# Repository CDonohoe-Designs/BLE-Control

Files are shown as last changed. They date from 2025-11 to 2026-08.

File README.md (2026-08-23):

# BLE-Control — Wearable BLE Controller

BLE-Control is a compact, low-power wearable controller built around the STM32WB55 (BLE 5 + Cortex-M4/M0+), designed with robust power delivery, RF performance, USB-C protection, and sensor interfacing in mind. The system includes a protected USB-C charging front end (PPTC, TVS, CMC, ESD), a TI BQ21061 charger/power-path, a clean 3.3 V system rail from TPS7A02, and a switchable sensor domain feeding TMP117, BMI270, and SHTC3. 

## PCB Render

<p align="center">
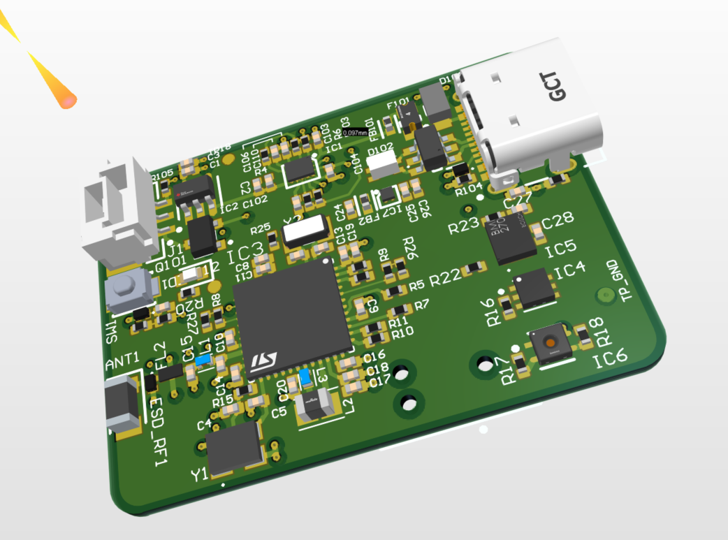
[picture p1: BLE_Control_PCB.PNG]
BLE Control PCB 3D render
  
</p>

## 2-Minute Engineering Review

I designed BLE-Control as a compact **low-power BLE wearable controller** that brings together power-path design, RF integration, USB-C protection, sensors and embedded bring-up considerations on one platform.

### Engineering focus

- **BLE embedded platform** — STM32WB55 dual-core MCU/radio architecture with SWD programming and BLE bring-up path
- **Power architecture** — BQ21061 charger/power path, low-noise 3.3 V regulation and a switchable sensor rail
- **USB-C robustness** — PPTC, TVS, ESD protection, common-mode filtering and controlled shield treatment
- **RF design intent** — STM32WB55 RF output, differential filtering, π-match provision, chip antenna and controlled RF routing strategy
- **Sensor integration** — TMP117, BMI270 and SHTC3 on a gated low-power domain
- **Bring-up planning** — staged verification of power, programming, charger, sensors, SMPS and RF performance
- **Design-for-test / EMC thinking** — test points, interface protection, return paths and pre-compliance checks considered during the hardware design

### Quick review

- **[Hardware / Altium source](Hardware/Altium/)**
- **[Documentation index](Docs/README.md)**
- **[Firmware area](Firmware/)**
- **[PCB render](BLE_Control_PCB.PNG)**

---

## ✔ Work Completed (More to do!)

## Project status

**Last updated:** _Nov 2025_ Summary

- ✅ **Schematic design**: Rev-A hierarchy complete (charger/LDO, MCU & RF, USB/debug, sensors, IO/buttons, testpoints).
- ✅ **First-pass BOM + docs**: Markdown BOM and design notes under `docs/`.
- ✅ **Standards & process docs**: ISO 13485 / ISO 14971 packs started; EMC/IEC alignment notes drafted.
- 🔄 **PCB layout (AD25)**: Stack-up and floorplanning in progress; routing and EMC tuning next.
- 🔄 **Design reviews**: EVT Rev-A sign-off checklists being filled in (schematic + PCB).
- ⏳ **Firmware & bring-up**: Basic STM32WB CubeIDE project to follow once PCB layout stabilises.

### **Hardware Design**
- Complete schematic capture in **Altium Designer 25**
- Power architecture finalised:
  - USB-C entry protection (PPTC, TVS, USBLC6, CMC, shield bleed)
  - BQ21061 charger/power-path wired and validated in schematic
  - TPS7A02-3.3 system rail finalised
  - TPS22910A sensor rail gating implemented
- Full RF chain designed:
  - STM32WB55 RF output → differential filter → π-match (DNP default) → chip antenna
  - CPWG routing strategy + via-fence defined
- Sensors subsystem defined (BMI270, TMP117, SHTC3)
- Tag-Connect TC2030-NL debug interface integrated

### **Documentation**
- `/Docs` folder structured like a mini Design History File

---

## My Roadmap

### **1. PCB Layout in Altium AD25**
- Stack-up definition (1.6 mm, 4-layer)
- Impedance-controlled CPWG for RF output
- SMPS layout (tight loop, ground islanding)
- USB-C differential routing & ESD return paths
- EMC placement discipline (TVS close to entry, CMC orientation, return paths)
- Placement of sensors & service loops for testing
- Test point optimisation

### **2. PCB DRC/EMC Review**
- High-speed/EMC checks (Rick Hartley rules)
- Return path verification
- Split of quiet vs noisy ccts
- Thermal considerations for charger IC

### **3. IEC / ISO Documentation Expansion**
- Full 60601-1 safety narrative 
- 60601-1-2 immunity for each port
- ISO 14971: expand risk register and residual risk justification
- ISO 13485: early DHF structure (revision control, traceability)

### **4. Firmware Bring-Up**
- Standby → Active → Sensor acquisition flow
- BLE service creation (GATT)
- BQ21061 telemetry/status decoding
- IMU & environmental sensing
- RF PER testing via CubeMonitor-RF

### **5. Pre-Compliance Preparation**
- Test plan for ESD/EFT/surge
- RF pre-scan (harmonics, match tuning)
- Power integrity measurements

This roadmap is updated as design work continues.

---

# Quick Navigation

###  Full Documentation 
→ **[`Docs/README.md`](Docs/README.md)**  
Structured like a mini **Design History File (DHF)**:

- Schematic (master PDF + overview)  
- Medical-style BoM + component-criticality  
- Safety boundary & 60601 rationale  
- EMC notes & port classification  
- Risk register (ISO 14971)  
- Battery pack documentation  
- Bring-up + AD25 rules

---

###  Hardware (Altium AD25)
→ **[`Hardware/Altium/`](Hardware/Altium/)**  

Includes:

- Complete AD25 project (`.PrjPcb`, `.SchDoc`, `.PcbDoc`)  
- Outputs, Draftsman drawings, OutJobs  
- Component libraries  
- SmartPDF source

---

###  Firmware (STM32WB55)
→ **[`Firmware/`](Firmware/)**  

- STM32CubeIDE project  
- BLE stack integration (CPU2 Wireless Coprocessor)  
- Startup & bring-up code  
- Board support notes

---

#  System Overview

BLE-Control contains three core domains:

### 1. Power / Charging / USB-C

- **BQ21061** charger/power-path  
- Reverse-battery PMOS  
- **TPS7A02-3.3** → `+3V3_SYS`  
- **TPS22910A** → `3V3_SENS` (gated sensor rail)  
- USB-C hardened with:  
  - PPTC  
  - VBUS TVS  
  - CC ESD  
  - USBLC6  
  - Common-mode choke  
  - Shield bleed `1 MΩ // 1 nF C0G`  

### 2. MCU + RF (STM32WB55)

- Dual-core + BLE 5  
- USB FS with 22 Ω series  
- 32 MHz HSE + 32.768 kHz LSE  
- On-chip SMPS with 10 µH + (optional 10 nH helper)  
- RF feed → π-match (DNP default) → Johanson antenna  
- SWD via **Tag-Connect TC2030-CTX-NL**

### 3. Sensors + I/O

- TMP117 (precision temperature)  
- BMI270 (IMU)  
- SHTC3 (humidity/T)  
- All on **3V3_SENS** gated by MCU  
- Button with ESD + RC + 100 Ω  
- LED indicator (active-low)  

---

#  Design-for-Compliance Highlights

*(Not certified; reflects professional habits and design intent)*

### IEC 60601-1 (Basic safety & essential performance)

- Full SELV design (<5.0 V)  
- Battery safety via BQ21061 + pack NTC  
- Reverse battery protection  
- Defined essential performance: **BLE command/control**

### IEC 60601-1-2 (Ed.4) EMC

- Classified ports (USB, button, sensor rail, RF)  
- Surge/ESD/EFT protection at USB entry  
- Segmented power domains for immunity (`3V3_SYS` vs `3V3_SENS`)  
- RF/SMPS layout discipline based on ST AN5165  

### ISO 14971 (Risk)

- Full risk register included  
- Hazards mapped to hardware controls  
- Residual-risk evaluation  
- Precompliance EMC test strategy  

### ISO 13485 (Documentation style)

Repo mirrors a simplified DHF structure:

```text
Docs/
  Schematic/
  BoM/
  Compliance/
  Risk/
  Battery/
  Reports/
  testing/
```

---
#  BLE-Control — Bring-Up & Testing Summary

This document captures the recommended bring-up flow and key test procedures for the BLE-Control hardware platform.

##  Bring-Up Order

### 1. **Verify Power Path & Rails**
- Power via USB-C or bench supply.
- Confirm:
  - `VBUS`
  - `VBAT_RAW`
  - `VBAT_PROT`
  - `PMID`
  - `+3V3_SYS` (TPS7A02 output)
- Check for ripple, inrush anomalies, or unstable startup.

### 2. **Flash STM32WB55 (SMPS-bypass mode)**
- Leave SMPS inductors populated or install 0 Ω bypass links.
- Program using Tag-Connect TC2030-CTX-NL.
- Load minimal firmware (heartbeat LED + UART/SWV optional).

### 3. **Enable Charger & Monitor `BQ_INT`**
- Validate:
  - USB attachment detection
  - Correct CC pull-down behaviour
  - BQ21061 charge state transitions
  - `BQ_INT` on MCU (falling-edge EXTI)

### 4. **Bring Up Sensors (`SENS_EN` → `3V3_SENS`)**
- Assert `SENS_EN` → TPS22910A enables the sensor rail.
- Confirm correct voltage and soft-start behaviour.
- Check I²C access to:
  - TMP117
  - BMI270
  - SHTC3

### 5. **Enable SMPS & Verify Ripple**
- Populate SMPS inductors (10 µH + optional 10 nH helper).
- Remove any bypass 0 Ω links if used.
- Measure ripple on:
  - `VLXSMPS`
  - `VDD`
  - `+3V3_SYS`

### 6. **RF Bring-Up + π-Match Tuning**
- Conduct preliminary RF tests:
  - Return-loss sweep of antenna
  - Harmonic scan
  - π-match population depending on results

### 7. **Run STM32CubeMonitor-RF PER Tests**
- Validate BLE link margin.
- Test across multiple channels.
- Measure Packet Error Rate (PER) at various distances and orientations.

---

##  EMC Pre-Compliance Checklist

### **IEC 61000-4-2 (ESD)**
- ±8 kV contact  
- ±15 kV air  
- Test:
  - USB shield
  - Button
  - Enclosure reference points

### **IEC 61000-4-4 (Burst/EFT)**
- ±1 kV at VBUS entry (through external PSU)

### **IEC 61000-4-3 (Radiated Immunity)**
- 10 V/m, 80 MHz–2.7 GHz  
- Observe:
  - BLE stability (RSSI)
  - Sensor I²C errors
  - Reset line behaviour
  - Spurious interrupts

### **IEC 61000-4-6 (Conducted RF Immunity)**
- 3 Vrms, 150 kHz–80 MHz  
- Monitor:
  - BLE performance  
  - I²C bus integrity  
  - Power rail droop

---

##  Tools Used

- **Altium Designer 25**  
- **STM32CubeIDE / STM32CubeProgrammer**  
- **LTspice / Python** (signal analysis, power ripple, FFT, etc.)  
- **STM32CubeMonitor-RF** (BLE PER, RSSI, channel sweep)  

---

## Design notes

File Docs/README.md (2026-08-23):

# BLE-Control — Documentation Index (`/Docs`)

This folder contains the supporting engineering documentation for the **BLE-Control low-power BLE sensor platform**.

The repository is organised as a practical portfolio / development record rather than a formal regulated-product technical file.

## Contents

- **Battery/** — battery pack requirements and interface notes
- **BoM/** — bill of materials and component information
- **Datasheets/** — manufacturer references and datasheet links
- **PCB/** — PCB-related notes and images
- **Reviews/** — schematic/design review checklists and follow-up actions
- **Schematic/** — exported schematic PDF

The documentation supports the hardware design, bring-up planning and verification work described in the main repository README.

> **Status:** engineering R&D / portfolio project. Not a certified or qualified medical device.

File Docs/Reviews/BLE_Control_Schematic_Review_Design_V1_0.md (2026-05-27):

# BLE-Control Schematic Design Review — Design Owner Checklist

**Project:** BLE-Control Wearable  
**Review Type:** Schematic Design Review  
**Review Basis:** BLE-Control schematic PDF, Altium schematic files, and PCB design file  
**Reviewer:** Caoilte Donohoe  
**Date:** 2026-05-27  
**Revision:**  A0 (EVT)

**Status:** Design-owner schematic review. Items marked as actions are follow-up checks before final release.

**Review Note:** This checklist records my  schematic review of the BLE-Control design. The ticked items indicate areas I reviewed against the schematic, with follow-up actions captured where further Altium, BOM, footprint, layout, or bring-up checks are required.

---

# 1. Documentation & Architecture

- [x] Reviewed  [ ] N/A — Schematic hierarchy is logical and easy to navigate  
  **My review:** Pass. The design is split into clear functional sheets: power/USB/charger, MCU/RF, and sensors/I/O.

- [x] Reviewed  [ ] N/A — Functional blocks are clearly separated  
  **My review:** Pass. Power, USB, charger, BLE RF, MCU, sensors, button and LED blocks are clearly grouped.

- [x] Reviewed  [ ] N/A — Design intent notes are included where appropriate  
  **My review:** Pass. Useful notes are included for BLE RF, USB protection, charger behaviour, BOOT0, SWD and sensor rail control.

- [x] Reviewed  [ ] N/A — Sheet titles and references are consistent  
  **My review:** Minor issue. Overall title structure is good, but the sensor sheet title/file text appears to contain a typo: `SchDDocrawn By`.  
  **My follow-up:** Clean up title block text before release.

- [x] Reviewed  [ ] N/A — Interfaces between sheets are clearly defined  
  **My review:** Pass. Cross-sheet signal labels are present for USB, I²C, sensor enable, interrupts, button and LED.

- [x] Reviewed  [ ] N/A — External interfaces are documented  
  **My review:** Pass. USB-C, battery connector, SWD and RF antenna sections are identifiable.

---

# 2. Power Architecture

- [x] Reviewed  [ ] N/A — Power architecture is clearly defined  
  **My review:** Pass. Main rails and sensor rail are understandable.

- [x] Reviewed  [ ] N/A — All supply rails have identified sources  
  **My review:** Pass. USB/VIN charging path, battery path, main 3V3 and gated sensor 3V3 are shown.

- [x] Reviewed  [ ] N/A — Voltage levels are appropriate for all devices  
  **My review:** Pass, with follow-up check. 3V3 system rail appears appropriate for MCU and sensors.  
  **My follow-up:** Check low-battery behaviour of the 3V3 LDO, as a single Li-ion cell may fall close to or below regulation headroom.

- [x] Reviewed  [ ] N/A — No missing power connections  
  **My review:** Pass, subject to compile check. Power pins are shown on visible symbols.  
  **My follow-up:** Run Altium compile/ERC and confirm.

- [x] Reviewed  [ ] N/A — Input protection strategy reviewed  
  **My review:** Pass. USB input includes PPTC, TVS/ESD and filtering.

- [x] Reviewed  [ ] N/A — Regulator enable behaviour reviewed  
  **My review:** Pass. LDO enable is tied to input and documented as always-on.

- [x] Reviewed  [ ] N/A — Startup behaviour reviewed  
  **My review:** Pass, with follow-up check. BOOT0, reset and sensor enable defaults are documented.  
  **My follow-up:** Confirm reset timing and firmware default states during bring-up.

---

# 3. Battery & Charging

- [x] Reviewed  [ ] N/A — Battery charging architecture reviewed  
  **My review:** Pass. Stand-alone Li-ion charger architecture is clear.

- [x] Reviewed  [ ] N/A — Charge current is appropriate  
  **My review:** Pass, with follow-up check. Charge current is documented as approximately 100 mA.  
  **My follow-up:** Check this matches intended battery capacity and charge-time expectations.

- [x] Reviewed  [ ] N/A — Battery connector reviewed  
  **My review:** Pass. Battery connector and protected battery node are shown.

- [x] Reviewed  [ ] N/A — NTC / temperature monitoring reviewed  
  **My review:** Pass, with follow-up check. Battery NTC connection is shown.  
  **My follow-up:** Confirm NTC divider/charger thermistor thresholds against battery pack datasheet.

- [x] Reviewed  [ ] N/A — Charger status signals reviewed  
  **My review:** Pass. PG/STAT signals are exposed and pulled up for debug.

- [x] Reviewed  [ ] N/A — Battery and charger test points included  
  **My review:** Pass. Charger status and power path test points are included.

---

# 4. MCU Review

- [x] Reviewed  [ ] N/A — MCU power pins connected correctly  
  **My review:** Pass, subject to compile check. Multiple VDD domains, RF supply and USB supply are shown.  
  **My follow-up:** Check against STM32WB55 reference design and ERC.

- [x] Reviewed  [ ] N/A — Decoupling strategy implemented  
  **My review:** Pass. Local 100 nF and bulk decoupling capacitors are included.

- [x] Reviewed  [ ] N/A — Reset circuit reviewed  
  **My review:** Pass. Pull-up and reset capacitor are shown.

- [x] Reviewed  [ ] N/A — Boot configuration reviewed  
  **My review:** Pass. BOOT0 is pulled down and documented.

- [x] Reviewed  [ ] N/A — Clock circuits reviewed  
  **My review:** Pass, minor issue noted. HSE and LSE circuits are shown.  
  **My follow-up:** Fix apparent capacitor value text typo: `10Fp` should likely be `10pF`. Check all crystal load capacitors against the crystal datasheet and STM32WB reference design.

- [x] Reviewed  [ ] N/A — Debug/programming interface included  
  **My review:** Pass. SWD/Tag-Connect service port is included.

- [x] Reviewed  [ ] N/A — Unused pins strategy considered  
  **My review:** Pass. Note states unused GPIO configured as analog/no-pull in firmware.

---

# 5. USB Interface

- [x] Reviewed  [ ] N/A — USB-C configuration reviewed  
  **My review:** Pass for USB 2.0 device/sink style implementation.

- [x] Reviewed  [ ] N/A — CC pin configuration reviewed  
  **My review:** Pass. CC pull-down resistors are included.

- [x] Reviewed  [ ] N/A — USB ESD protection included  
  **My review:** Pass. USB data and CC ESD protection are included.

- [x] Reviewed  [ ] N/A — USB filtering reviewed  
  **My review:** Pass, with follow-up check. Common-mode choke is included.  
  **My follow-up:** Check selected CMC is suitable for USB full-speed signalling and does not degrade eye margin.

- [x] Reviewed  [ ] N/A — VBUS protection reviewed  
  **My review:** Pass. VBUS includes fuse and TVS protection.

- [x] Reviewed  [ ] N/A — USB data path reviewed  
  **My review:** Pass, with follow-up check. Series resistors are included at MCU side.  
  **My follow-up:** Check USB-C D+/D− A/B side connection symmetry and differential routing in PCB.

---

# 6. RF / BLE Review

- [x] Reviewed  [ ] N/A — RF signal path clearly defined  
  **My review:** Pass. STM32WB RF pin routes through matching/filtering to chip antenna.

- [x] Reviewed  [ ] N/A — Antenna selection reviewed  
  **My review:** Pass, with follow-up check. Chip antenna is included.  
  **My follow-up:** Check board thickness, ground clearance and antenna keepout match antenna datasheet.

- [x] Reviewed  [ ] N/A — RF matching network included  
  **My review:** Pass. Matching/filter components are included.

- [x] Reviewed  [ ] N/A — RF ESD protection included  
  **My review:** Pass, with follow-up check. RF ESD footprint is included.  
  **My follow-up:** Check RF ESD capacitance is low enough for 2.4 GHz operation and locate close to antenna/RF entry as intended.

- [x] Reviewed  [ ] N/A — Controlled impedance requirement documented  
  **My review:** Pass. RF path is labelled as 50 ohm / CPWG intent.

- [x] Reviewed  [ ] N/A — Antenna keepout requirement documented  
  **My review:** Pass, with follow-up check. RF notes exist.  
  **My follow-up:** Check keepout in the PCB file against antenna datasheet.

- [x] Reviewed  [ ] N/A — RF grounding strategy considered  
  **My review:** Pass. Via fence / CPWG strategy is documented.

- [x] Reviewed  [ ] N/A — EMC / radiated emissions strategy considered  
  **My review:** Pass. RF and IEC 60601-1-2 intent notes are included.

---

# 7. Sensors & Interfaces

- [x] Reviewed  [ ] N/A — I²C bus architecture reviewed  
  **My review:** Pass. I²C bus connects MCU, temperature sensor and IMU.

- [x] Reviewed  [ ] N/A — Pull-up strategy reviewed  
  **My review:** Pass. Pull-ups are connected to gated sensor rail.

- [x] Reviewed  [ ] N/A — Address conflicts checked  
  **My review:** Reviewed, follow-up required. Address pins are visible, but full address review requires datasheets.  
  **My follow-up:** Confirm TMP117 and BMI270 I²C addresses do not conflict.

- [x] Reviewed  [ ] N/A — Sensor power requirements reviewed  
  **My review:** Pass. Sensors are powered from gated 3V3 sensor rail.

- [x] Reviewed  [ ] N/A — Sensor enable strategy reviewed  
  **My review:** Pass. Sensor rail is controlled through load switch.

- [x] Reviewed  [ ] N/A — Interrupt handling reviewed  
  **My review:** Pass, with follow-up check. Interrupt lines are shown.  
  **My follow-up:** Check required pull-ups/pull-downs and firmware configuration.

---

# 8. User Interface

- [x] Reviewed  [ ] N/A — Button default states defined  
  **My review:** Pass. Pull network and default state are documented.

- [x] Reviewed  [ ] N/A — Button debounce strategy reviewed  
  **My review:** Pass. RC filtering is included.

- [x] Reviewed  [ ] N/A — Button ESD protection included  
  **My review:** Pass. TVS/ESD diode is included.

- [x] Reviewed  [ ] N/A — LED current limiting reviewed  
  **My review:** Pass. LED resistor is included.

- [x] Reviewed  [ ] N/A — LED drive method reviewed  
  **My review:** Pass. LED is MCU-controlled.

- [x] Reviewed  [ ] N/A — LED default state reviewed  
  **My review:** Pass, with follow-up check.  
  **My follow-up:** Check firmware default GPIO state prevents unwanted LED current during reset.

---

# 9. EMC / ESD Review

- [x] Reviewed  [ ] N/A — External interfaces protected  
  **My review:** Pass. USB, button and RF interfaces include protection.

- [x] Reviewed  [ ] N/A — Human-accessible interfaces protected  
  **My review:** Pass. USB and button include ESD protection.

- [x] Reviewed  [ ] N/A — RF interface protected  
  **My review:** Pass, with follow-up check. RF ESD is included.

- [x] Reviewed  [ ] N/A — USB interface protected  
  **My review:** Pass. USB ESD/TVS/fuse/CMC are present.

- [x] Reviewed  [ ] N/A — Filtering strategy reviewed  
  **My review:** Pass. USB filtering, ferrite beads and RF filtering are included.

- [x] Reviewed  [ ] N/A — Noise-sensitive circuits identified  
  **My review:** Pass. RF, crystal and sensor sections are identifiable.  
  **My follow-up:** Check layout keeps RF/crystal loops short and away from noisy USB/power paths.

---

# 10. Grounding Strategy

- [x] Reviewed  [ ] N/A — Grounding philosophy documented  
  **My review:** Pass. Notes refer to RF grounding, CPWG and via fence.

- [x] Reviewed  [ ] N/A — Digital return paths considered  
  **My review:** Reviewed, to confirm during PCB review.  
  **My follow-up:** Confirm solid L2 ground plane and no routing across return path gaps.

- [x] Reviewed  [ ] N/A — RF grounding considered  
  **My review:** Pass with PCB verification required.  
  **My follow-up:** Check RF via fence, antenna keepout and matching network grounding in layout.

- [x] Reviewed  [ ] N/A — Shielding requirements identified  
  **My review:** Not currently required for this BLE-Control prototype unless enclosure or system shielding is added later.

- [x] Reviewed  [ ] N/A — No obvious unintended ground issues identified  
  **My review:** Pass, subject to compile check.  
  **My follow-up:** Check with compiled project/net connectivity.

---

# 11. Testability

- [x] Reviewed  [ ] N/A — Power rail test points available  
  **My review:** Pass. Main rails and charger nodes have test points.

- [x] Reviewed  [ ] N/A — Ground test points available  
  **My review:** Pass. Ground test point is included.

- [x] Reviewed  [ ] N/A — Debug access available  
  **My review:** Pass. SWD connector is included.

- [x] Reviewed  [ ] N/A — Key signals accessible  
  **My review:** Pass. Charger status, boot, sensor enable and rails are accessible.

- [x] Reviewed  [ ] N/A — Programming method defined  
  **My review:** Pass. SWD/Tag-Connect is documented as service port.

- [x] Reviewed  [ ] N/A — Manufacturing test access considered  
  **My review:** Pass for prototype.  
  **My follow-up:** For production, define fixture access, programming flow and minimum functional test.

---

# 12. Reliability & Robustness

- [x] Reviewed  [ ] N/A — Safe startup behaviour reviewed  
  **My review:** Pass. BOOT0, reset and sensor enable behaviour are documented.

- [x] Reviewed  [ ] N/A — Safe shutdown behaviour reviewed  
  **My review:** Reviewed, follow-up required.  
  **My follow-up:** Check firmware handles low battery and charger connection behaviour.

- [x] Reviewed  [ ] N/A — Brownout conditions considered  
  **My review:** Reviewed, follow-up required.  
  **My follow-up:** Check STM32 brownout/reset configuration and low-battery behaviour.

- [x] Reviewed  [ ] N/A — Fault behaviour reviewed  
  **My review:** Pass at schematic level. Sensor rail can be disabled.

- [x] Reviewed  [ ] N/A — Recovery behaviour reviewed  
  **My review:** Pass, with follow-up check. SWD and BOOT0 recovery path are available.

---

# 13. Manufacturing Readiness

- [x] Reviewed  [ ] N/A — Components available from suitable suppliers  
  **My review:** Reviewed, BOM follow-up required.  
  **My follow-up:** Review lifecycle, lead time and alternates.

- [x] Reviewed  [ ] N/A — Lifecycle risk reviewed  
  **My review:** Reviewed, BOM follow-up required.  
  **My follow-up:** Add lifecycle and AVL review before release.

- [x] Reviewed  [ ] N/A — Footprints verified  
  **My review:** Reviewed, footprint/library follow-up required.  
  **My follow-up:** Verify all footprints against datasheets, especially USB-C, antenna, STM32 package, charger, load switch and connectors.

- [x] Reviewed  [ ] N/A — Assembly risks identified  
  **My review:** Reviewed, PCB/DFM follow-up required.  
  **My follow-up:** Check small passives, USB-C solderability, antenna clearance and connector accessibility.

- [x] Reviewed  [ ] N/A — Special manufacturing requirements identified  
  **My review:** Partially reviewed. RF antenna/matching and USB-C assembly need specific DFM attention.

---

# 14. Key Review Findings

## Major Issues

- [x] No major schematic issues identified in my review.
- [ ] Issue: _______________________________________

## Minor Issues / Fix Before Release

- [x] Fix apparent title block typo on sensor sheet.
- [x] Check apparent capacitor value text typo: `10Fp` should likely be `10pF`.
- [x] Check USB-C D+/D− A/B side connectivity and routing symmetry.
- [x] Check RF antenna keepout, ground clearance and antenna reference layout.
- [x] Confirm crystal load capacitors against crystal and STM32WB55 requirements.
- [x] Confirm LDO dropout/headroom at low battery voltage.
- [x] Run Altium compile/ERC and resolve all relevant warnings/errors.
- [x] Verify all footprints against component datasheets.
- [x] Generate BOM/lifecycle/AVL review.

## Recommendations

- [x] Add a short `Review Notes` section to the repository explaining that this is an EVT non-medical wearable prototype.
- [x] Export ERC report from Altium and store it with this checklist.
- [x] Export schematic PDF and PCB screenshots after each release tag.
- [x] Add a small production/bring-up checklist covering first power-up, SWD programming, BLE test, USB test, charger test and sensor I²C scan.

---

# Final Sign-Off

| Reviewer | Role | Status | Date |
|---|---|---|---|
| Caoilte Donohoe | Design Owner | [ ] Approved [x] Conditional [ ] Reject | 2026-05-27 |
| Reviewer 2 | Peer Reviewer | [ ] Approved [ ] Conditional [ ] Reject | __________ |

**Conditional Approval Note:**  
I consider the schematic suitable for prototype/EVT progression, subject to Altium compile/ERC, footprint verification, RF antenna layout check, USB-C connectivity check, and BOM/lifecycle review.

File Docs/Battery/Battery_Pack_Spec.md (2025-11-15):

# BLE-Control Battery Pack Specification

**Type:** Single-cell Li-ion polymer (3.7 V nom, 4.2 V max)  
**Capacity:** 300–500 mAh (target ~400 mAh)  
**Wires:** 3-wire (VBAT+, GND, 10 k NTC @25 °C, B≈3435)  
**Protection:** Integrated PCM (OVP/UVP/OCP/short)  
**Connector:** JST-GH, 3-pin (Board: BM03B-GHS-TBT; Cable: GHR-03V-S + SSHL-003GA-P0.2)

## Compliance & Documentation (Required)
- IEC 62133-2 certificate/report (cell or pack)
- UN 38.3 transport test report
- UL 2054 (or equivalent safety report) – preferred for pack
- MSDS, RoHS/REACH, CoC, traceability labels

## Electrical
- Max charge voltage: 4.2 V
- Recommended charge current: 0.2–0.5 C
- Discharge current: ≥0.2 A continuous, ≥0.5 A peak
- Operating temp (charge): 0…45 °C (JEITA via BQ21061 TS)
- Storage temp: –20…45 °C

## Pinout (J102 / JST-GH-3)
1: VBAT+ (red)  
2: GND (black)  
3: NTC 10 k (white)

## Notes
- Pack NTC is mandatory for medical-minded design; the charger TS pin reads pack temperature for JEITA-safe charging.
- Harness length: 50–150 mm, strain-relieved.

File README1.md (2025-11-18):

# BLE-Control — Wearable BLE Controller

BLE-Control is a compact, low-power wearable controller built around the STM32WB55 (BLE 5 + Cortex-M4/M0+), designed with robust power delivery, RF performance, USB-C protection, and sensor interfacing in mind. The system includes a protected USB-C charging front end (PPTC, TVS, CMC, ESD), a TI BQ21061 charger/power-path, a clean 3.3 V system rail from TPS7A02, and a switchable sensor domain feeding TMP117, BMI270, and SHTC3. It acts as an external BLE-enabled controller/companion board suitable for wearable, low-profile and medically-aligned designs.

This is a portfolio/showcase project with **design-for-compliance** habits intentionally aligned to **IEC 60601-1** (basic safety & essential performance), **IEC 60601-1-2 Ed.4** (EMC, Class A), and documentation practices informed by **ISO 13485** (QMS) and **ISO 14971** (risk).  
The repository mirrors a lightweight **Design History File** structure: schematic and BoM, safety & EMC rationale, port classification, risk register, battery documentation, and bring-up/test notes are all traceable from the `/Docs` directory.

> *Design-for-compliance only — not a medical device.*
## ✔ Work Completed (So Far)

## Project status

**Last updated:** _Nov 2025_ Summary

- ✅ **Schematic design**: Rev-A hierarchy complete (charger/LDO, MCU & RF, USB/debug, sensors, IO/buttons, testpoints).
- ✅ **First-pass BOM + docs**: Markdown BOM and design notes under `docs/`.
- ✅ **Standards & process docs**: ISO 13485 / ISO 14971 packs started; EMC/IEC alignment notes drafted.
- 🔄 **PCB layout (AD25)**: Stack-up and floorplanning in progress; routing and EMC tuning next.
- 🔄 **Design reviews**: EVT Rev-A sign-off checklists being filled in (schematic + PCB).
- ⏳ **Firmware & bring-up**: Basic STM32WB CubeIDE project to follow once PCB layout stabilises.

This project is actively developed. Current completed items:

### **Hardware Design**
- Complete schematic capture in **Altium Designer 25**
- Power architecture finalised:
  - USB-C entry protection (PPTC, TVS, USBLC6, CMC, shield bleed)
  - BQ21061 charger/power-path wired and validated in schematic
  - TPS7A02-3.3 system rail finalised
  - TPS22910A sensor rail gating implemented
- Full RF chain designed:
  - STM32WB55 RF output → differential filter → π-match (DNP default) → chip antenna
  - CPWG routing strategy + via-fence defined
- Sensors subsystem defined (BMI270, TMP117, SHTC3)
- All MCU pins given **deterministic biasing** (no floating pins)
- Tag-Connect TC2030-NL debug interface integrated

### **Documentation**
- `/Docs` folder structured like a mini Design History File
- Medical-style BoM with component criticality assigned
- IEC 60601-1 electrical safety overview drafted
- IEC 60601-1-2 EMC port classification completed
- ISO 14971 risk register created
- Battery pack documentation (IEC 62133-2 & UN 38.3 expectations)
- Bring-up & test notes written (PER testing, EMC behaviours)

### **Repo Structure**
- Root README reworked for reviewer-friendly navigation  
- SmartPDF schematic published  
- Clear folder structure: Docs / Hardware / Firmware  

---

## 🚧 What’s Next (Roadmap)

### **1. PCB Layout in Altium AD25**
- Stack-up definition (0.8 mm, 4-layer)
- Impedance-controlled CPWG for RF output
- SMPS layout (tight loop, ground islanding)
- USB-C differential routing & ESD return paths
- EMC placement discipline (TVS close to entry, CMC orientation, return paths)
- Placement of sensors & service loops for testing
- Test point optimisation

### **2. PCB DRC/EMC Review**
- High-speed/EMC checks (Rick Hartley rules)
- Return path verification
- Split of quiet vs noisy domains
- Thermal considerations for charger IC

### **3. IEC / ISO Documentation Expansion**
- Full 60601-1 safety narrative (MOP, essential performance, failure modes)
- 60601-1-2 immunity rationale for each port
- ISO 14971: expand risk register and residual risk justification
- ISO 13485: early DHF structure (revision control, traceability)

### **4. Firmware Bring-Up**
- Standby → Active → Sensor acquisition flow
- BLE service creation (GATT)
- BQ21061 telemetry/status decoding
- IMU & environmental sensing
- RF PER testing via CubeMonitor-RF

### **5. Pre-Compliance Preparation**
- Test plan for ESD/EFT/surge
- RF pre-scan (harmonics, match tuning)
- Power integrity measurements

This roadmap is updated as design work continues.

##  Repository Structure Overview

```text
BLE-Control/
│
├── Docs/                ← Main documentation hub
│   ├── Schematic/
│   ├── BoM/
│   ├── Compliance/
│   ├── Battery/
│   ├── Risk/
│   ├── Reports/
│   └── testing/
│
├── Hardware/
│   └── Altium/          ← Full AD25 hardware project
│
├── Firmware/            ← STM32WB55 firmware (CubeIDE)
│
└── LICENSE_MIT
```

---

# Quick Navigation

###  Full Documentation (start here)
→ **[`Docs/README.md`](Docs/README.md)**  
Structured like a mini **Design History File (DHF)**:

- Schematic (master PDF + overview)  
- Medical-style BoM + component-criticality  
- Safety boundary & 60601 rationale  
- EMC notes & port classification  
- Risk register (ISO 14971)  
- Battery pack documentation  
- Bring-up + AD25 rules

---

###  Hardware (Altium AD25)
→ **[`Hardware/Altium/`](Hardware/Altium/)**  

Includes:

- Complete AD25 project (`.PrjPcb`, `.SchDoc`, `.PcbDoc`)  
- Outputs, Draftsman drawings, OutJobs  
- Component libraries  
- SmartPDF source

---

###  Firmware (STM32WB55)
→ **[`Firmware/`](Firmware/)**  

- STM32CubeIDE project  
- BLE stack integration (CPU2 Wireless Coprocessor)  
- Startup & bring-up code  
- Board support notes

---

###  Key Engineering Docs

- **Schematic (PDF):**  
  → [`Docs/Schematic/BLE-Control_Schematic_Master.pdf`](Docs/Schematic/BLE-Control_Schematic_Master.pdf)

- **Medical BoM:**  
  → [`Docs/BoM/BLE-Control_Medical_BoM.md`](Docs/BoM/BLE-Control_Medical_BoM.md)

- **Risk Register:**  
  → [`Docs/Risk/Risk_Register.md`](Docs/Risk/Risk_Register.md)

- **EMC Notes:**  
  → [`Docs/Reports/EMC_Precompliance_Notes.md`](Docs/Reports/EMC_Precompliance_Notes.md)

---

#  System Overview

BLE-Control contains three core domains:

### 1. Power / Charging / USB-C

- **BQ21061** charger/power-path  
- Reverse-battery PMOS  
- **TPS7A02-3.3** → `+3V3_SYS`  
- **TPS22910A** → `3V3_SENS` (gated sensor rail)  
- USB-C hardened with:  
  - PPTC  
  - VBUS TVS  
  - CC ESD  
  - USBLC6  
  - Common-mode choke  
  - Shield bleed `1 MΩ // 1 nF C0G`  

### 2. MCU + RF (STM32WB55)

- Dual-core + BLE 5  
- USB FS with 22 Ω series  
- 32 MHz HSE + 32.768 kHz LSE  
- On-chip SMPS with 10 µH + (optional 10 nH helper)  
- RF feed → π-match (DNP default) → Johanson antenna  
- SWD via **Tag-Connect TC2030-CTX-NL**

### 3. Sensors + I/O

- TMP117 (precision temperature)  
- BMI270 (IMU)  
- SHTC3 (humidity/T)  
- All on **3V3_SENS** gated by MCU  
- Button with ESD + RC + 100 Ω  
- LED indicator (active-low)  

---

#  Design-for-Compliance Highlights

*(Not certified; reflects professional habits and design intent)*

### IEC 60601-1 (Basic safety & essential performance)

- Full SELV design (<5.0 V)  
- Battery safety via BQ21061 + pack NTC  
- Reverse battery protection  
- Defined essential performance: **BLE command/control**

### IEC 60601-1-2 (Ed.4) EMC

- Classified ports (USB, button, sensor rail, RF)  
- Surge/ESD/EFT protection at USB entry  
- Segmented power domains for immunity (`3V3_SYS` vs `3V3_SENS`)  
- RF/SMPS layout discipline based on ST AN5165  

### ISO 14971 (Risk)

- Full risk register included  
- Hazards mapped to hardware controls  
- Residual-risk evaluation  
- Precompliance EMC test strategy  

### ISO 13485 (Documentation style)

Repo mirrors a simplified DHF structure:

```text
Docs/
  Schematic/
  BoM/
  Compliance/
  Risk/
  Battery/
  Reports/
  testing/
```

---
#  BLE-Control — Bring-Up & Testing Summary

This document captures the recommended bring-up flow and key test procedures for the BLE-Control hardware platform.

##  Recommended Bring-Up Order

### 1. **Verify Power Path & Rails**
- Power via USB-C or bench supply.
- Confirm:
  - `VBUS`
  - `VBAT_RAW`
  - `VBAT_PROT`
  - `PMID`
  - `+3V3_SYS` (TPS7A02 output)
- Check for ripple, inrush anomalies, or unstable startup.

### 2. **Flash STM32WB55 (SMPS-bypass mode)**
- Leave SMPS inductors populated or install 0 Ω bypass links.
- Program using Tag-Connect TC2030-CTX-NL.
- Load minimal firmware (heartbeat LED + UART/SWV optional).

### 3. **Enable Charger & Monitor `BQ_INT`**
- Validate:
  - USB attachment detection
  - Correct CC pull-down behaviour
  - BQ21061 charge state transitions
  - `BQ_INT` on MCU (falling-edge EXTI)

### 4. **Bring Up Sensors (`SENS_EN` → `3V3_SENS`)**
- Assert `SENS_EN` → TPS22910A enables the sensor rail.
- Confirm correct voltage and soft-start behaviour.
- Check I²C access to:
  - TMP117
  - BMI270
  - SHTC3

### 5. **Enable SMPS & Verify Ripple**
- Populate SMPS inductors (10 µH + optional 10 nH helper).
- Remove any bypass 0 Ω links if used.
- Measure ripple on:
  - `VLXSMPS`
  - `VDD`
  - `+3V3_SYS`

### 6. **RF Bring-Up + π-Match Tuning**
- Conduct preliminary RF tests:
  - Return-loss sweep of antenna
  - Harmonic scan
  - π-match population depending on results

### 7. **Run STM32CubeMonitor-RF PER Tests**
- Validate BLE link margin.
- Test across multiple channels.
- Measure Packet Error Rate (PER) at various distances and orientations.

---

##  EMC Pre-Compliance Checklist

### **IEC 61000-4-2 (ESD)**
- ±8 kV contact  
- ±15 kV air  
- Test:
  - USB shield
  - Button
  - Enclosure reference points

### **IEC 61000-4-4 (Burst/EFT)**
- ±1 kV at VBUS entry (through external PSU)

### **IEC 61000-4-3 (Radiated Immunity)**
- 10 V/m, 80 MHz–2.7 GHz  
- Observe:
  - BLE stability (RSSI)
  - Sensor I²C errors
  - Reset line behaviour
  - Spurious interrupts

### **IEC 61000-4-6 (Conducted RF Immunity)**
- 3 Vrms, 150 kHz–80 MHz  
- Monitor:
  - BLE performance  
  - I²C bus integrity  
  - Power rail droop

---

##  Tools Used

- **Altium Designer 25**  
- **STM32CubeIDE / STM32CubeProgrammer**  
- **LTspice / Python** (signal analysis, power ripple, FFT, etc.)  
- **STM32CubeMonitor-RF** (BLE PER, RSSI, channel sweep)  

---

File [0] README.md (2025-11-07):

# BLE-Control — Wearable BLE Control Board (Altium AD25) 

**BLE-Control** is a small, low-power wearable control board **I built** around the **STM32WB55** (BLE 5 + Cortex-M4).  
This is a **portfolio/showcase design I intentionally aligned** to **IEC 60601-1** (basic safety & essential performance) and **IEC 60601-1-2 Ed.4** (EMC, **Class A** – professional healthcare environment) practices, with documentation patterns influenced by **ISO 13485** (QMS) and **ISO 14971** (risk management). It is a Work in Progress 
> *Not a claim of compliance; design-for-compliance focus only.*

## Table of contents
- [EDA environment](#eda-environment)
- [Highlights](#highlights)
- [Medical-minded protection & EMC (Class A focus)](#medical-minded-protection--emc-class-a-focus)
- [How this repo aligns with medical standards (plain-English)](#how-this-repo-aligns-with-medical-standards-plain-english)
  - [IEC 60601-1 — Basic safety & essential performance](#iec-60601-1--basic-safety--essential-performance)
  - [IEC 60601-1-2 (Ed.4) — EMC (Class A)](#iec-60601-1-2-ed4--emc-class-a)
  - [ISO 13485 — Quality system (how I organize the work)](#iso-13485--quality-system-how-i-organize-the-work)
  - [ISO 14971 — Risk management](#iso-14971--risk-management)
- [Documentation](#documentation)
- [Datasheets & Notes](#datasheets--notes)
- [Quick start (Altium AD25)](#quick-start-altium-ad25)
- [Schematic partition (what lives where)](#schematic-partition-what-lives-where)
- [Power & ground rules (STM32WBxx)](#power--ground-rules-stm32wbxx)
  - [Rails](#rails)
  - [On-chip SMPS cell](#on-chip-smps-cell)
  - [Layout essentials](#layout-essentials)
- [Debug (TC2030 — Cortex/SWD)](#debug-tc2030--cortexswd)
  - [Handy hook table](#handy-hook-table)
- [BOM & releases](#bom--releases)
- [STM32CubeIDE Firmware (STM32WB55CG, UFQFPN-48)](#stm32cubeide-firmware-stm32wb55cg-ufqfpn-48)
- [Bring-up sequence (what I do first)](#bring-up-sequence-what-i-do-first)
- [Antenna tune checklist (π-match)](#antenna-tune-checklist-π-match)
- [Lightweight risk log (template I keep)](#lightweight-risk-log-template-i-keep)
- [Links & resources](#links--resources)
- [Change summary](#change-summary)

---
## EDA environment
- **Altium Designer 25.3.3 build 18**
---

## Highlights
- **MCU:** STM32WB55CGU6 (BLE 5.0 + Cortex-M4)
- **Power:** Single-cell Li-Po, **TI BQ25180** ultra-low-Iq charger (USB-C sink) with **ship-mode** +  **TPS22910A** gated sensor rail
- **Sensors:** **BMI270** (6-axis IMU), **MAX17048** (fuel gauge, always-on), **SHTC3** (temp+RH, switched)
- **RF:** 2.4 GHz **chip antenna** with **π-match ** with **LPF DLF162500LT-5028A1** and optional **RF ESD**
- **Debug:** **Tag-Connect TC2030-NL** (Cortex/SWD) — I don’t need USB D+/D− for programming
- **I/O:** 1× tactile button, 1× status LED, expansion pads (I²C/SPI/3V3/GND)
- **Form factor:** 4-layer, 0.8 mm PCB, **0402 passives** (0603 only for bulk/ESD)
- **Regulatory focus:** I designed toward **IEC 60601-1** and **60601-1-2 Class A**; docs follow **ISO 13485** / **ISO 14971** patterns

---

## Medical-minded protection & EMC (Class A focus)
> Goal: apply sensible protections and layout habits so **IEC 60601-1-2 Ed.4 (Class A)** pre-compliance is predictable. I document these as risk controls per **ISO 14971**.  
> *Showcase only; not a certified device.*

- **USB-C (charging port)**
  - **VBUS TVS** at the receptacle; shortest return to GND
  - **D+/D− ESD** array adjacent to pins
  - **CC1/CC2 ESD** (low-C) within a few mm
  - **Shield bleed:** **1 MΩ // 1 nF (C0G)** shell→GND
  - **CMC on D+/D− (DNP)** unless I enable USB data
- **RF feed (2.4 GHz)**
  - **Ultra-low-C RF ESD (DNP)** pad to GND; π-match footprints (DNP) for post-tune; via-fence along CPWG
- **Buttons / test pads**
  - **Small ESD TVS** at touch point; **100 Ω** series at the MCU pin
- **Power / grounding**
  - L2 **solid GND**; via-in-pad under MCU EPAD; **tight SMPS loop**; bead-isolated **+3V3_ANA** (or direct with local decoupling)
- **ESD test intent**
  - Design targets **±8 kV contact / ±15 kV air** (IEC 61000-4-2) at touch points; returns share the same stitching path as the touched metal
- **Risk mgmt hooks (ISO 14971)**
  - TVS, series resistors, shield bleed, reverse-battery PMOS, VBAT limits captured as **risk controls** with planned verification steps

---

## How this repo aligns with medical standards (plain-English)

**My goal:** demonstrate the “design-for-compliance” habits a medical team expects.  
*Showcase, not a certification claim.*

### IEC 60601-1 — Basic safety & essential performance
- **Ask:** user/patient safety (shock, burn, mechanical, fire); protect “essential performance.”
- **Do:** SELV only + **external medical-grade PSU** for charging; reverse-battery PMOS; conservative creepage/clearance for 3.3 V; VBAT_MCU ≤ 3.6 V; derating; define **essential performance** (BLE control path) and test it.

### IEC 60601-1-2 (Ed.4) — EMC (Class A)
- **Ask:** withstand ESD/RF fields and limit emissions (hospital/clinical environment).
- **Do:** ESD entry control (VBUS TVS, D+/D− ESD, **CC-line ESD**, **shield R//C**); solid GND plane, **tight SMPS loop**, RF via-fence, crystal “island”; call out zap points/pass criteria (±8 kV/±15 kV).

### ISO 13485 — Quality system (how I organize the work)
- **Ask:** controlled processes, traceability, planned V&V, documented changes.
- **Do:** Structured docs, BOM with MPNs, checklists, OutJobs/releases, linked datasheets/app notes, relative paths for reproducibility.

### ISO 14971 — Risk management
- **Ask:** hazards → risks → controls → verify → residual risk.
- **Do:** Treat TVS/series-R/shield-bleed/reverse-battery/VBAT limits/RF keepouts as **risk controls**; map each to a **verification** (ESD gun, continuity, brown-out); keep a lightweight **risk log**.

**Bottom line**
- **60601-1** = safety → low-voltage domain + protective circuits  
- **60601-1-2 Class A** = EMC → ESD/EMI features + RF-aware layout  
- **ISO 13485** = process → controlled, reproducible outputs  
- **ISO 14971** = risk → explicit mitigations + verification

---

## Documentation
- **Wearable Schematic Guide:** [Docs/BLE-Control_Wearable_Schematic_Guide_AD25_v2.md](BLE-Control_Wearable_Schematic_Guide_AD25_v2.md)  
- **Power & Ground Rules (STM32WBxx):** [Docs/BLE-Control_Power_Ground_Rules.md](Docs/BLE-Control_Power_Ground_Rules.md)  
- **Build Plan (AD25):** [Docs/BLE-Control_Build_Plan_AD25.md](Docs/BLE-Control_Build_Plan_AD25.md)  
- **One-Page Connection Checklist:** [Docs/BLE-Control_Connection_Checklist_OnePage.md](Docs/BLE-Control_Connection_Checklist_OnePage.md)  
- **Grouped BOM:** [Docs/BoM/BLE-Control_BOM_Grouped.md](Docs/BLE-Control_BOM_Grouped.md)  
- **CubeMonitor-RF test flow:** [Docs/testing/BLE_Control_CubeMonitorRF_Testing.md](Docs/testing/BLE_Control_CubeMonitorRF_Testing.md)

---

## Datasheets & Notes
- **TI BQ25180 — Ultra-low-Iq charger (USB-C sink):** [Docs/Datasheets/TI_BQ25180_Datasheet.pdf](Docs/Datasheets/TI_BQ25180_Datasheet.pdf)  
- **TI TPS7A02-3V3 — Ultra-low-Iq LDO:** [Docs/Datasheets/TI_TPS7A02_Datasheet.pdf](Docs/Datasheets/TI_TPS7A02_Datasheet.pdf)  
- **TI TPS22910A — Load switch (active-low):** [Docs/Datasheets/TI_TPS22910A_Datasheet.pdf](Docs/Datasheets/TI_TPS22910A_Datasheet.pdf)  
- **STM32WB55xx Datasheet:** [Docs/Datasheets/stm32wb55xx_datasheet.pdf](Docs/Datasheets/stm32wb55xx_datasheet.pdf)  
- **AN5165 — STM32WB RF hardware guidelines:** [Docs/Datasheets/AN5165_RF_Hardware_STM32WB.pdf](Docs/Datasheets/AN5165_RF_Hardware_STM32WB.pdf)  
- **BQ21061 EVM User Guide (SLUUC59) — reference for BQ21062 alt:** https://www.ti.com/lit/ug/sluuc59/sluuc59.pdf

---

## Quick start (Altium AD25)
1. Open **`Hardware/Altium/BLE_Control.PrjPcb`**.
2. **Libraries**
   - **Integrated:** compile `Libraries/Integrated/*.LibPkg` → install via **Components → (gear) File-based Libraries**.
   - **Database:** open `Libraries/DBLib/BLE_Control.DBLib` (status **Connected**). Map to **Library Ref / Library Path / Footprint**; DB at `Libraries/Database/BLE_Control_Parts_DB.xlsx`.
3. Place parts on `Schematic/*.SchDoc`. **Project → Validate** → proceed to `BLE_Control.PcbDoc`.

---

## Schematic partition (what lives where)
- **Power_Charge_USB.SchDoc** — **BQ25180** charger (USB-C sink, ship-mode), **TPS22910A** sensor rail (**VDD_SENS**), **TPS7A02-3V3**, thermistor input, **USB shield R//C bleed**, **CC ESD**  
- **MCU_RF.SchDoc** — **STM32WB55**, HSE 32 MHz & LSE 32.768 kHz, **on-chip SMPS cell** (L1=10 µH + optional 10 nH), decoupling, **RF π-match (DNP)**, **optional RF ESD (DNP)**, SWD pins  
USB-C receptacle, **5.1 kΩ Rd** on CC1/CC2 (sink-only), ESD, optional USB-FS path, **Tag-Connect TC2030-NL** (Cortex/SWD)  
- **IO_Buttons_LEDs.SchDoc** — Button (ESD + 100 Ω series), status LED  
- **Sensors.SchDoc** — **BMI270** (INT1/2→EXTI), **MAX17048** (always-on @ VBAT), **SHTC3** (on **VDD_SENS**), I²C pull-ups

---

## Power & ground rules (STM32WBxx)

### Rails
- **`VDD = VDDRF = VDDSMPS = +3V3_SYS`** (single 3V3 domain)
- **VBAT (MCU backup):** **I have not ** tied to Li-ion (3.0–4.2 V). **Net-tie to +3V3_SYS** with **100 nF**.  
  Naming hygiene: **`VBAT_MCU`** (pin) vs **`VBATT`** (pack)

### On-chip SMPS cell
- **Path:** `+3V3_SYS → L1 (10 µH for 4 MHz; 2.2 µH for 8 MHz) → [optional 10 nH] → VLXSMPS`
- **Decoupling:**  
  - `VFBSMPS → 4.7 µF → GND` **at pins** (not a system rail)  
  - `VDDSMPS → (4.7 µF + 0.1 µF) → GND` **at pins**
- **BYPASS option:** provide **0 Ω links** so `VDDSMPS/VLXSMPS/VFBSMPS` can be shorted to `VDD` for initial LDO bring-up

### Layout essentials
- **Tiny SMPS loop**; keep **VLXSMPS** short & wide; no RF/clock under-routes  
- **Crystal islands:** guard to GND, short tracks, symmetric loads; keep LSE away from RF  
- **RF CPWG:** clear keepout, via-fence, DNP π-match

---

## Debug (TC2030 — Cortex/SWD)

**Pin map (top view pads `1 2 3 / 4 5 6`):**  
**1=VTref (3V3 sense)**, **2=SWDIO (PA13)**, **3=GND**, **4=SWCLK (PA14)**, **5=nRESET (NRST)**, **6=SWO (PB3, optional)**

- Keep SWDIO/SWCLK/NRST **short, single-via** if possible; place near edge  
- **No paste** on pads; include **3 NPTH alignment holes**  
- Power target from board supply; VTref is **sense** only

### Handy hook table

| TC2030 Pad | Signal | Suggested Net | STM32WB55 Pin | Required | Notes |
|---:|---|---|---|:---:|---|
| 1 | VTref | +3V3_SYS | — | ✅ | Probe voltage sense; does not power target |
| 2 | SWDIO | SWDIO | PA13 | ✅ | Short trace; no series R |
| 3 | GND | GND | — | ✅ | Stitching via next to pad |
| 4 | SWCLK | SWCLK | PA14 | ✅ | Short trace; no series R |
| 5 | nRESET | NRST | NRST | ✅ | 10 k→3V3 + 100 nF→GND optional |
| 6 | SWO | SWO | PB3 | ✅ | Optional SWV printf/trace |

---

## BOM & releases
- **Grouped BOM:** includes **L1 = 10 µH** (main SMPS), **L1A = 10 nH (DNP)** series helper, **CC-line ESD**, **USB shield R//C**, **button ESD + 100 Ω**, **RF ESD (DNP)** → [Docs/BOM/BLE-Control_BOM_Grouped.md](Docs/BoM/BLE-Control_BOM_Grouped.md)  
- **Releases:** OutJob produces PDFs, fab/assy, XY, and BOM packages

**Inductor picks** (as used/documented)
- **10 µH (L1):** Murata **LQM21FN100M70L** (0805). Alt: Coilcraft **XFL2010-103MEC**  
- **10 nH (L1A, optional):** Murata **LQW15AN10NG00D** (0402). Alt: TDK **MLG1005S10NHT000**  
- **8 MHz SMPS mode** option: **2.2 µH** (e.g., Würth **74479774222**) in place of 10 µH

---

## STM32CubeIDE Firmware (STM32WB55CG, UFQFPN-48)
**Project path:** `Firmware/BLE_Control/` → **[Open Firmware README](Firmware/BLE_Control/README.md)**  
**Goal:** self-contained CubeIDE project that anyone can import and build.

**Toolchain (tested):** STM32CubeIDE 1.17.0 · STM32CubeWB (specify version) · STM32CubeProgrammer (specify)

**Wireless coprocessor (CPU2):**
- Use **STM32CubeProgrammer → Wireless/FUS** to flash the **BLE stack** (Full/Light/Concurrent).  
- Record the **stack version** in the Firmware README under *Toolchain / versions*.

---

## Bring-up sequence (what I do first)
1. **Power path only:** charger + LDO rails up; verify **+3V3_SYS** ripple/overshoot; VBAT_MCU tied to 3V3 with 100 nF  
2. **MCU in LDO/BYPASS:** 0 Ω short the SMPS nodes; flash minimal firmware over SWD; heartbeat LED + SWV  
3. **Peripherals one-by-one:** I²C pull-ups ok; IMU/ALERT/INT lines; fuel gauge read; button interrupt  
4. **Enable SMPS:** populate **L1 (10 µH)** (+ optional **10 nH**), remove 0 Ω shorts; confirm stability & current draw  
5. **RF phase:** π-match DNP → populate after VNA/tune; verify PER with **STM32CubeMonitor-RF** ([guide](Docs/testing/BLE_Control_CubeMonitorRF_Testing.md))

---

## Antenna tune checklist (π-match)
- Confirm stack-up & CPWG impedance; check ground fence  
- Sniff-test near-field; check harmonics with SMPS on/off  
- Populate C-L-C to meet return-loss target across BLE channels  
- Lock values; **freeze keepout** and update BOM

---

## Lightweight risk log (template I keep)
| Hazard | Sequence of events | Harm | Control | Verification | Residual risk |
|---|---|---|---|---|---|
| ESD into USB | User touch during charge | Loss of function | TVS on VBUS, D+/D−, CC; shield R//C | IEC 61000-4-2 at shell & pins | Acceptable |
| Reverse battery | Wrong insertion | Board damage | PMOS ideal-diode | Polarity test, brown-out | Acceptable |
| Over-voltage VBAT_MCU | Tied to Li-ion | MCU damage | VBAT_MCU ≤ 3.3 V, 100 nF | DMM, power-off retention | Acceptable |
| RF desense | SMPS spur coupling | Reduced link margin | 10 nH helper, layout rules | PER across channels | Acceptable |

---

## Links & resources
- **AN5165 — STM32WB RF hardware guidelines:** [Docs/Datasheets/AN5165_RF_Hardware_STM32WB.pdf](Docs/Datasheets/AN5165_RF_Hardware_STM32WB.pdf)  
- **Phil’s Lab #139 — PCB Chip Antenna Hardware Design:** https://www.youtube.com/watch?v=UQBMROv7Dy4  
- **STM32WB Getting Started playlist:** https://www.youtube.com/playlist?list=PLnMKNibPkDnG9JRe2fbOOpVpWY7E4WbJ-  

---

### Change summary
- Switched charger to **BQ25180**; documented ship-mode and sink-only USB-C
- Added **SMPS cell** details (10 µH + optional 10 nH), **VBAT caution**, naming hygiene
- Fixed **TC2030** mapping (Cortex/SWD)
- Baked in **medical-minded ESD/EMC** practices and risk-control notes
- Linked **AN5165** and **Grouped BOM**; added bring-up & tuning checklists

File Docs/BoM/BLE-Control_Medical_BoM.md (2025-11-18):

# BLE-Control — Medical-Grade Bill of Materials (BoM)

**Document ID:** BLEC-BOM-A3  
**Revision:** A3  
**Device:** BLE-Control Wearable BLE Controller  
**Prepared by:** C. Donohoe  
**Standards:** IEC 60601-1, IEC 60601-1-2, ISO 13485, ISO 14971  

---

## 1. Criticality Classes

- **A — Safety-Critical** (electrical safety, battery, current limiting, surge/ESD)  
- **B — EMC-Critical** (RF match, CMC, ferrite, shield bleed)  
- **C — Function-Critical** (MCU, BLE, sensors, core passives)  
- **D — Non-Critical** (UI, indicators, documentation-only items, mechanical)

---

## 2. Full BoM (with MPNs, including passives)

> **Note:** For generic passives, MPNs are defined as **internal codes**  
> (e.g. `BLEC-R-0402-4K70-1%`), which can be mapped to a preferred vendor series  
> (Yageo RC0402FR-07…, Murata GRM155…, etc.) in your AVL.

| Cat. | Qty | Designator(s) | Function | Value / Part | Package | Manufacturer | MPN | Notes |
|---|-----|---|---|---|---|---|-----|---|
| B | 1 | ANT1 | BLE antenna | 2450AT18A100E | 3.2×1.6 | Johanson | 2450AT18A100E | RF front-end |
| C | 6 | C1, C2, C24, C26, C103, C104 | Bulk/decoupling | 1 µF, 10 V, X5R | 0402 | Internal | **BLEC-C-0402-1u0-10V-X5R** | Pref: Murata GRM155R61A105K |
| C | 10 | C3, C9, C10, C11, C12, C13, C16, C17, C19, C23 | Local decoupling | 100 nF, 16 V, X7R | 0402 | Internal | **BLEC-C-0402-100n-16V-X7R** | Pref: Murata GRM155R71C104K |
| C | 3 | C8, C18, C20 | Bulk | 4.7 µF, 10 V, X5R | 0402 | Internal | **BLEC-C-0402-4u7-10V-X5R** | LDO/charger bulk |
| B | 1 | C14 | RF π-match | 0.8 pF | 0402 | Murata | GRM1555C1HR80BA01D | RF match C1 |
| B | 1 | C15 | RF π-match | 0.3 pF | 0402 | Murata | GRM1555C1HR30WA01D | RF match C2 |
| C | 1 | C21 | HSE load C | 10 pF | 0402 | Internal | **BLEC-C-0402-10p-25V-C0G** | Pref: GRM1555C1H100JA01 |
| C | 1 | C22 | LSE load C | 10 pF | 0402 | Internal | **BLEC-C-0402-10p-25V-C0G** | LSE crystal load |
| C | 4 | C25, C27, C28, C29 | RC/decoupling | 100 nF | 0402 | Internal | **BLEC-C-0402-100n-16V-X7R** | BTN RC, local decoupling |
| C | 2 | C101, C110 | Filter/snubber | 1 nF | 0402 | Internal | **BLEC-C-0402-1n0-50V-X7R** | Burst/EMC use |
| C | 1 | C102 | Bulk | 22 µF | 0402 | Internal | **BLEC-C-0402-22u-6V3-X5R** | Main 3V3 bulk |
| C | 2 | C105, C106 | LDO decoupling | 2.2 µF | 0402 | Internal | **BLEC-C-0402-2u2-10V-X5R** | TPS7A02/BQ support |
| A | 4 | D3, ESD_CC1, ESD_CC2, ESD_RF1 | ESD protection | PESD5V0S1UL,315 | SOD-323 | Nexperia | PESD5V0S1UL,315 | CC, BTN, RF ESD |
| A | 1 | D101 | VBUS TVS | SMF5.0AT1G | SOD-123FL | onsemi | SMF5.0AT1G | Surge/ESD on VBUS |
| A | 1 | D102 | USB ESD array | USBLC6-2SC6Y | SOT-23-6 | STMicro | USBLC6-2SC6Y | USB D+/D- ESD |
| A | 1 | F101 | PPTC fuse | MF-PSMF050X-2 | 0805 | Bourns | MF-PSMF050X-2 | 500 mA resettable |
| B | 2 | FB2, FB101 | Ferrite beads | 120 Ω @100 MHz | 0402 | Murata | BLM15AG121SN1D | Conducted RF filter |
| B | 1 | FL2 | RF filter | DLF162500LT-5028A1 | 1608 | TDK | DLF162500LT-5028A1 | Differential RF filter |
| B | 1 | FL101 | USB CMC | ACM2012D-900-2P-T00 | 0805 | TDK | ACM2012D-900-2P-T00 | USB CM choke |
| A | 1 | IC1 | Charger/PMIC | BQ21061YFPR | BGA20 | TI | BQ21061YFPR | Li-ion charger/safety |
| A | 1 | IC2 | 3.3V LDO | TPS7A0233PDBVR | SOT23-5 | TI | TPS7A0233PDBVR | 3V3 system rail |
| C | 1 | IC3 | MCU + BLE | STM32WB55CGU6 | QFN48 | STMicro | STM32WB55CGU6 | Core logic/radio |
| C | 1 | IC4 | Temp sensor | TMP117NAIDRVR | SON-6 | TI | TMP117NAIDRVR | Precision temperature |
| C | 1 | IC5 | IMU | BMI270 | QFN | Bosch | BMI270 | 6-axis IMU |
| C | 1 | IC6 | Humidity sensor | SHTC3 | QFN | Sensirion | SHTC3 | RH & temp |
| B | 1 | IC7 | Load switch | TPS22910AYZVR | BGA4 | TI | TPS22910AYZVR | Gated 3V3_SENS |
| D | 1 | J1 | Battery conn. | BM03B-GHS-TBT (LF)(SN)(N) | 3-pin | JST | BM03B-GHS-TBT | Li-Po connector |
| A | 1 | J2 | USB-C connector | USB4105-GF-A | - | GCT | USB4105-GF-A | Primary IEC 60601 port |
| D | 1 | J3 | SWD connector | TC2030-CTX-NL | - | Tag-Connect | TC2030-CTX-NL | Service-only debug |
| B | 1 | L1 | RF inductor | 2.7 nH | 0402 | Murata | (per LQW15 series) | RF π-match L |
| C | 1 | L2 | Power inductor | 10 µH | 0805 | Murata | (LQM21FN series) | LDO/charger inductor |
| B | 1 | L3 | RF inductor | 10 nH | 0402 | Murata | LQG15HS2N7S02 or equiv. | RF network |
| D | 1 | LED1 | Status LED | 19-217_GHC-YR1S2_3T | 0603 | Everlight | 19-217_GHC-YR1S2_3T | Indicator |
| A | 1 | Q101 | Reverse FET | SSM3J332R,LF | SOT-23 | Toshiba | SSM3J332R,LF | Battery reverse protection |
| D | 2 | R1, R104 | USB CC | 5.1 kΩ, 1% | 0402 | Internal | **BLEC-R-0402-5K10-1%** | Pref: Yageo RC0402FR-075K1L |
| C | 4 | R2, R9, R17, R18 | I2C pull-up | 4.7 kΩ, 1% | 0402 | Internal | **BLEC-R-0402-4K70-1%** | I2C SYS/SENS pulls |
| B | 8 | R3, R6, R22, R23, R25, R103, R109, R110 | Bias pulls | 100 kΩ, 1% | 0402 | Internal | **BLEC-R-0402-100K-1%** | Biasing GPIO/CE/etc. |
| C | 1 | R4 | BQ_INT pull-up | 47 kΩ, 1% | 0402 | Internal | **BLEC-R-0402-47K0-1%** | INT line pull |
| B | 4 | R10, R11, R12, R13 | Series resistors | 22 Ω, 1% | 0402 | Internal | **BLEC-R-0402-22R0-1%** | USB/signal damping |
| C | 3 | R14, R16, R19 | Reset/alert pulls | 10 kΩ, 1% | 0402 | Internal | **BLEC-R-0402-10K0-1%** | NRST/TMP/BQ pulls |
| D | 2 | R15, R105 | Zero-ohm links | 0 Ω | 0402 | Internal | **BLEC-R-0402-0R00** | Config links |
| C | 1 | R20 | LED resistor | 1 kΩ, 1% | 0402 | Internal | **BLEC-R-0402-1K00-1%** | LED current set |
| C | 1 | R21 | Button pull-up | 470 kΩ, 1% | 0402 | Internal | **BLEC-R-0402-470K-1%** | BTN bias |
| C | 1 | R24 | BTN series | 100 Ω, 1% | 0402 | Internal | **BLEC-R-0402-100R-1%** | EMC on button line |
| B | 2 | R101, R107 | Shield bleed | 1 MΩ, 1% | 0402 | Internal | **BLEC-R-0402-1M00-1%** | Shield R in R//C network |
| C | 1 | SW1 | Tactile switch | B3U-1000P | SMD | Omron | B3U-1000P | User pushbutton |
| D | 1 | TP1 | Electrical TP: USB_VBUS | N/A (net marker only) | N/A | N/A | N/A | Documentation-only |
| D | 2 | TP2, TP17 | Electrical TPs | N/A (TestPoint nets) | N/A | N/A | N/A | Documentation-only |
| D | 1 | TP3 | Electrical TP: VIN_BQ | N/A | N/A | N/A | N/A | Documentation-only |
| D | 1 | TP4 | Electrical TP: VBATT_RAW | N/A | N/A | N/A | N/A | Documentation-only |
| D | 1 | TP5 | Electrical TP: VBAT_PROT | N/A | N/A | N/A | N/A | Documentation-only |
| D | 1 | TP6 | Electrical TP: GND | N/A | N/A | N/A | N/A | Documentation-only |
| D | 1 | TP7 | Electrical TP: +3V3_SYS | N/A | N/A | N/A | N/A | Documentation-only |
| D | 1 | TP8 | Electrical TP: BQ_INT | N/A | N/A | N/A | N/A | Documentation-only |
| D | 1 | TP9 | Electrical TP: LSLDO | N/A | N/A | N/A | N/A | Documentation-only |
| D | 1 | TP10 | Electrical TP: CE_MCU | N/A | N/A | N/A | N/A | Documentation-only |
| D | 1 | TP11 | Electrical TP: BAT_NTC_10K | N/A | N/A | N/A | N/A | Documentation-only |
| D | 1 | TP12 | Electrical TP: 3V3_SENS | N/A | N/A | N/A | N/A | Documentation-only |
| D | 1 | TP13 | Electrical TP: USB_FS_R_P | N/A | N/A | N/A | N/A | Documentation-only |
| D | 1 | TP14 | Electrical TP: SENS_EN | N/A | N/A | N/A | N/A | Documentation-only |
| D | 1 | TP15 | Electrical TP: USB_FS_R_N | N/A | N/A | N/A | N/A | Documentation-only |
| D | 1 | TP16 | Electrical TP: VDD | N/A | N/A | N/A | N/A | Documentation-only |
| C | 1 | Y1 | HSE crystal | 32 MHz | NX3225SA | NDK | NX3225SA-32MHZ-EXS00A-CS02368 | Main clock |
| C | 1 | Y2 | LSE crystal | 32.768 kHz | ABS07 | Abracon | ABS07-32.768KHZ-7-T | RTC clock |

---

_End of BLE-Control_Medical_BoM.md_

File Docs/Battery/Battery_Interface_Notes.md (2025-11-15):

# Battery Interface Notes

- TS (BQ21061) wired to pack NTC via 0 Ω link; 
- CE, LP, MR default pulls to +3V3_SYS (100 k).
- LSLDO remains a distinct output; ≥2.2 µF close to pin; not tied to +3V3_SYS.
- Test points: TP_VBAT, TP_BAT_NTC, TP_3V3, TP_CE, TP_INT.

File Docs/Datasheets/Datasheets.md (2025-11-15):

# BLE-Control — BOM Datasheet Links (Major Components)

Below are manufacturer datasheets (and official product pages where helpful) grouped by schematic section.

---

## MCU-RF

- **MCU — STM32WB55CGU6 (ST)**  
  Datasheet: https://www.st.com/resource/en/datasheet/stm32wb55cc.pdf  
  Product page: https://www.st.com/en/microcontrollers-microprocessors/stm32wb55cg.html

- **On-chip SMPS Inductor — LQM21FN100M70L (Murata, 10 µH, 0805)**  
  Product page: https://www.murata.com/en-us/products/productdetail?partno=LQM21FN100M70L

- **SMPS helper inductor — LQW15AN10NG00D (Murata, 10 nH, 0402)**  
  Product page: https://www.murata.com/en-us/products/productdetail?partno=LQW15AN10NG00D

- **2.4 GHz Chip Antenna — 2450AT18A100 (Johanson Technology)**  
  Datasheet: https://www.johansontechnology.com/docs/1129/2450AT18A100E-AEC_tCZ7Fpd.pdf

- **u.FL RF test jack — U.FL-R-SMT-1(10) (Hirose)**  
  Series catalog: https://www.hirose.com/en/product/document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

- **RF ESD diode — PESD5V0S1UL (Nexperia, SOD882)**  
  Datasheet: https://assets.nexperia.com/documents/data-sheet/PESD5V0S1UL.pdf

- **Low Pass Filter -  TDK DLF162500LT-5028A1 (0603 LTCC low-pass filter for the 2.4 GHz band)**
  Datasheet: https://product.tdk.com/en/search/rf/rf/filter/info?part_no=DLF162500LT-5028A1

- **HSE crystal — NX3225SA-32MHz-STD-CSR-3 (NDK 3.2×2.5 mm)**  
  Series datasheet: https://www.ndk.com/images/products/catalog/c_NX3225SA_e.pdf

- **LSE crystal — ABS07-32.768KHZ-7-T (Abracon 3.2×1.5 mm)**  
  Product page: https://abracon.com/parametric/crystals/ABS07-32.768KHZ-7-T  
  Datasheet: https://abracon.com/Resonators/ABS07.pdf

- **Tag-Connect SWD — TC2030-NL**  
  Product page: https://www.tag-connect.com/product/tc2030-nl

---

## Power_Charge_USB

- **1-cell Li-ion charger — BQ21062YFPR (TI)**  
  Product page / docs: https://www.ti.com/product/BQ21062

- **Reverse-battery P-MOSFET — SSM3J332R,LF (Toshiba) (alt: DMG2305UX-13, Diodes Inc.)**  
  Toshiba datasheet: https://toshiba.semicon-storage.com/info/docget.jsp?did=16305  
  Diodes Inc. datasheet (alt): https://www.diodes.com/assets/Datasheets/DMG2305UX.pdf

- **USB-C receptacle — USB4105-GF-A (GCT)**  
  Datasheet: https://gct.co/files/specs/usb4105-spec.pdf  
  Product page: https://gct.co/connector/usb4105

- **USB ESD array — USBLC6-2SC6 (ST)**  
  Datasheet: https://www.st.com/resource/en/datasheet/usblc6-2sc6y.pdf  
  Product page: https://estore.st.com/en/products/protections-and-emi-filters/esd-protection/general-purpose-esd-protection/usblc6-2.html

- **USB common-mode choke — ACM2012D-900-2P-T00 (TDK)**  
  Product page: https://product.tdk.com/en/search/emc/emc/cmf_cmc/info?part_no=ACM2012D-900-2P-T00

- **VBUS TVS — SMF5.0A (Littelfuse, SOD-123FL)**  
  Product page: https://www.littelfuse.com/products/overvoltage-protection/tvs-diodes/surface-mount/smf/smf5-0a

- **Polyfuse — MF-MSMF050/16 (Bourns, 1206)**  
  Series datasheet: https://www.bourns.com/docs/product-datasheets/mf-msmf.pdf

- **JST Li-Po connector — BM02B-GHS-TBT (GH series, 1.25 mm)**  
  GH series catalog: https://www.jst-mfg.com/product/pdf/eng/eGH.pdf

- **Charger NTC — NCP15XH103F03RC (Murata 10 k, 0402)**  
  Product page: https://www.murata.com/en-eu/products/productdetail?partno=NCP15XH103F03RC

---

## Sensor

### Bosch BMI270 (IMU)
- **Datasheet:** https://www.bosch-sensortec.com/media/boschsensortec/downloads/datasheets/bst-bmi270-ds000.pdf
- **Shuttle Board 3.0 (schematic/overview):** https://docs.rs-online.com/32e4/A700000008845135.pdf
- **Handling / Soldering / Mounting Guide:** https://www.mouser.com/pdfDocs/BST-BMI270-HS000.pdf

### Sensirion SHTC3 (Temp/RH)
- **Datasheet:** https://sensirion.com/media/documents/643F9C8E/63A5A436/Datasheet_SHTC3.pdf
- **Eval Kit – SEK-SHTC3-Sensors:** https://www.mouser.com/ProductDetail/Sensirion/SEK-SHTC3-Sensors
- **SensorBridge Technical Guide:** https://sensirion.com/media/documents/7F4762CB/642D8327/SEK-SensorBridge_Technical_Guide_D1.pdf
- **Design-in Guide (SHT/STS family):** https://sensirion.com/media/documents/FC5BED84/61644655/Sensirion_Temperature_Sensors_Design_Guide_V1.pdf

---

## Sensor — Skin Temperature (Digital)

### Texas Instruments TMP117 (±0.1 °C)
- **Datasheet:** https://www.ti.com/lit/gpn/TMP117
- **EVM User Guide (schematic/BOM):** https://www.ti.com/lit/ug/snou161/snou161.pdf
- **Reference Design – TIDA-060034 (hearables ear temp flex):** https://www.ti.com/tool/TIDA-060034
- **App Note – Precise Temp Measurements (TMP116/117):** https://www.ti.com/lit/pdf/snoa986

- **Variant — MAX30208 (Analog Devices / Maxim, ±0.1 °C)**  
  Product page / datasheet: https://www.analog.com/en/products/max30208.html

---

## IO_Buttons_LED

- **Green LED — 19-217/GHC-YR1S2/3T (Everlight, 0603/1608)**  
  Datasheet: https://www.mouser.com/datasheet/2/143/19-217-GHC-YR1S2-3T-1663276.pdf

- **Tact switch — KMR221GLFS (C&K)**  
  Product page / datasheet: https://www.ckswitches.com/products/switches/product-details/Tactile/KMR2/KMR221GLFS/

---

## Key Application Notes & Guides

- **ST AN6044 — Ultralow power system design guidelines & STEVAL-ASTRA1B power management characterization**  
  PDF: https://www.st.com/resource/en/application_note/an6044-ultralow-power-system-design-guidelines-and-stevalastra1b-power-management-characterization-stmicroelectronics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

- **ST AN5156 — Introduction to security for STM32 MCUs**  
  PDF: https://www.st.com/resource/en/application_note/an5156-introduction-to-security-for-stm32-mcus-stmicroelectronics.pdf

- **BQ21061EVM — Evaluation Module User’s Guide (TI)**  
  Official PDF: https://www.ti.com/lit/ug/sluuc59/sluuc59.pdf  
  **Repo copy (your Docs/Datasheets):** https://github.com/CDonohoe-Designs/BLE-Control/blob/main/Docs/Datasheets/BQ21061EVM%20Evaluation%20Module%20User's%20Guide.pdf

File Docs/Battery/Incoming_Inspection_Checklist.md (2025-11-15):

# Incoming Inspection – Battery Packs

- Verify label: voltage, capacity, lot, date
- Check pinout vs. JST-GH: 1=VBAT, 2=GND, 3=NTC
- Measure open-circuit voltage: 3.7–3.9 V typical on receipt
- Measure NTC at 25 °C: ≈10 kΩ (±5%)
- Visual: pouch damage, leads strain relief, insulation
- Documentation present: IEC 62133-2, UN 38.3, UL 2054/MSDS

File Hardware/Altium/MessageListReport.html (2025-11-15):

Altium customize

# Message List

Date: | | 13/11/2025
Time: | | 23:28:42
Elapsed Time: | | 00:00:00

Class | Document | Source | Message | Time | Date | No.
[Error] | MCU_RF.SchDoc | Compiler | Duplicate Net Names Wire +3V3_SYS | 23:28:21 | 13/11/2025 | 1
[Error] | Power_Charge_USB.SchDoc | Compiler | Duplicate Net Names Wire +3V3_SYS | 23:28:21 | 13/11/2025 | 2
[Error] | MCU_RF.SchDoc | Compiler | Duplicate Net Names Wire BMI270_INT1 | 23:28:21 | 13/11/2025 | 3
[Error] | MCU_RF.SchDoc | Compiler | Duplicate Net Names Wire BMI270_INT2 | 23:28:21 | 13/11/2025 | 4
[Error] | MCU_RF.SchDoc | Compiler | Duplicate Net Names Wire BTN1 | 23:28:21 | 13/11/2025 | 5
[Error] | MCU_RF.SchDoc | Compiler | Duplicate Net Names Wire CE_MCU | 23:28:21 | 13/11/2025 | 6
[Error] | MCU_RF.SchDoc | Compiler | Duplicate Net Names Wire GND | 23:28:21 | 13/11/2025 | 7
[Error] | Power_Charge_USB.SchDoc | Compiler | Duplicate Net Names Wire GND | 23:28:21 | 13/11/2025 | 8
[Error] | MCU_RF.SchDoc | Compiler | Duplicate Net Names Wire I2C3_SENS_SCL | 23:28:21 | 13/11/2025 | 9
[Error] | MCU_RF.SchDoc | Compiler | Duplicate Net Names Wire I2C3_SENS_SDA | 23:28:21 | 13/11/2025 | 10
[Error] | MCU_RF.SchDoc | Compiler | Duplicate Net Names Wire I2C_CHG_SCL | 23:28:21 | 13/11/2025 | 11
[Error] | MCU_RF.SchDoc | Compiler | Duplicate Net Names Wire I2C_CHG_SDA | 23:28:21 | 13/11/2025 | 12
[Error] | MCU_RF.SchDoc | Compiler | Duplicate Net Names Wire LED_STAT_N | 23:28:21 | 13/11/2025 | 13
[Error] | MCU_RF.SchDoc | Compiler | Duplicate Net Names Wire SENS_EN | 23:28:21 | 13/11/2025 | 14
[Error] | MCU_RF.SchDoc | Compiler | Duplicate Net Names Wire TMP117_ALERT | 23:28:21 | 13/11/2025 | 15
[Error] | MCU_RF.SchDoc | Compiler | Duplicate Net Names Wire USB_FS_R_N | 23:28:21 | 13/11/2025 | 16
[Error] | MCU_RF.SchDoc | Compiler | Duplicate Net Names Wire USB_FS_R_P | 23:28:21 | 13/11/2025 | 17
[Error] | Sensor_IO_Buttons_LED.SchDoc | Compiler | Net +3V3_SYS has only one pin (Pin FB2-1) | 23:28:21 | 13/11/2025 | 18
[Error] | MCU_RF.SchDoc | Compiler | Net [USB_FS_R_N] is used in more than one differential pair objects : [USB_FS_R] [USB_FS_R] | 23:28:21 | 13/11/2025 | 19
[Error] | MCU_RF.SchDoc | Compiler | Net [USB_FS_R_P] is used in more than one differential pair objects : [USB_FS_R] [USB_FS_R] | 23:28:21 | 13/11/2025 | 20
[Error] | MCU_RF.SchDoc | Compiler | Net BMI270_INT1 has only one pin (Pin IC2-9) | 23:28:21 | 13/11/2025 | 21
[Error] | MCU_RF.SchDoc | Compiler | Net BMI270_INT2 has only one pin (Pin IC2-10) | 23:28:21 | 13/11/2025 | 22
[Error] | MCU_RF.SchDoc | Compiler | Net BTN1 has only one pin (Pin IC2-29) | 23:28:21 | 13/11/2025 | 23
[Error] | Power_Charge_USB.SchDoc | Compiler | Net CE_MCU has only one pin (Pin IC1-C2) | 23:28:21 | 13/11/2025 | 24
[Error] | MCU_RF.SchDoc | Compiler | Net CE_MCU has only one pin (Pin IC2-18) | 23:28:21 | 13/11/2025 | 25
[Error] | MCU_RF.SchDoc | Compiler | Net I2C3_SENS_SCL has only one pin (Pin IC2-16) | 23:28:21 | 13/11/2025 | 26
[Error] | MCU_RF.SchDoc | Compiler | Net I2C3_SENS_SDA has only one pin (Pin IC2-44) | 23:28:21 | 13/11/2025 | 27
[Error] | Power_Charge_USB.SchDoc | Compiler | Net I2C_CHG_SCL has only one pin (Pin IC1-E3) | 23:28:21 | 13/11/2025 | 28
[Error] | Power_Charge_USB.SchDoc | Compiler | Net I2C_CHG_SDA has only one pin (Pin IC1-E2) | 23:28:21 | 13/11/2025 | 29
[Error] | MCU_RF.SchDoc | Compiler | Net LED_STAT_N has only one pin (Pin IC2-28) | 23:28:21 | 13/11/2025 | 30
[Error] | Sensor_IO_Buttons_LED.SchDoc | Compiler | Net LED_STAT_N has only one pin (Pin LED1-1) | 23:28:21 | 13/11/2025 | 31
[Error] | MCU_RF.SchDoc | Compiler | Net SENS_EN has only one pin (Pin IC2-17) | 23:28:21 | 13/11/2025 | 32
[Error] | Sensor_IO_Buttons_LED.SchDoc | Compiler | Net SENS_EN has only one pin (Pin IC4-B2) | 23:28:21 | 13/11/2025 | 33
[Error] | MCU_RF.SchDoc | Compiler | Net TMP117_ALERT has only one pin (Pin IC2-11) | 23:28:21 | 13/11/2025 | 34
[Error] | Power_Charge_USB.SchDoc | Compiler | Net USB_FS_R_N has only one pin (Pin FL101-4) | 23:28:21 | 13/11/2025 | 35
[Error] | MCU_RF.SchDoc | Compiler | Net USB_FS_R_N has only one pin (Pin R10-2) | 23:28:21 | 13/11/2025 | 36
[Error] | Power_Charge_USB.SchDoc | Compiler | Net USB_FS_R_P has only one pin (Pin FL101-3) | 23:28:21 | 13/11/2025 | 37
[Error] | MCU_RF.SchDoc | Compiler | Net USB_FS_R_P has only one pin (Pin R11-2) | 23:28:21 | 13/11/2025 | 38
[Error] | MCU_RF.SchDoc | Compiler | Port +3V3_SYS not matched to Sheet Entry at 12.07mm,165.1mm | 23:28:21 | 13/11/2025 | 39
[Error] | Sensor_IO_Buttons_LED.SchDoc | Compiler | Port +3V3_SYS not matched to Sheet Entry at 17.78mm,154.94mm | 23:28:21 | 13/11/2025 | 40
[Error] | Power_Charge_USB.SchDoc | Compiler | Port +3V3_SYS not matched to Sheet Entry at 162.31mm,145.29mm | 23:28:21 | 13/11/2025 | 41
[Error] | MCU_RF.SchDoc | Compiler | Port BMI270_INT1 not matched to Sheet Entry at 160.02mm,139.7mm | 23:28:21 | 13/11/2025 | 42
[Error] | Sensor_IO_Buttons_LED.SchDoc | Compiler | Port BMI270_INT1 not matched to Sheet Entry at 168.91mm,78.74mm | 23:28:21 | 13/11/2025 | 43
[Error] | MCU_RF.SchDoc | Compiler | Port BMI270_INT2 not matched to Sheet Entry at 160.02mm,137.16mm | 23:28:21 | 13/11/2025 | 44
[Error] | Sensor_IO_Buttons_LED.SchDoc | Compiler | Port BMI270_INT2 not matched to Sheet Entry at 259.08mm,81.28mm | 23:28:21 | 13/11/2025 | 45
[Error] | Sensor_IO_Buttons_LED.SchDoc | Compiler | Port BTN1 not matched to Sheet Entry at 73.66mm,55.88mm | 23:28:21 | 13/11/2025 | 46
[Error] | MCU_RF.SchDoc | Compiler | Port BTN1 not matched to Sheet Entry at 160.66mm,93.98mm | 23:28:21 | 13/11/2025 | 47
[Error] | Power_Charge_USB.SchDoc | Compiler | Port CE_MCU not matched to Sheet Entry at 56.13mm,123.44mm | 23:28:21 | 13/11/2025 | 48
[Error] | MCU_RF.SchDoc | Compiler | Port CE_MCU not matched to Sheet Entry at 160.66mm,116.84mm | 23:28:21 | 13/11/2025 | 49
[Error] | Sensor_IO_Buttons_LED.SchDoc | Compiler | Port I2C3_SENS_SCL not matched to Sheet Entry at 25.4mm,104.14mm | 23:28:21 | 13/11/2025 | 50
[Error] | MCU_RF.SchDoc | Compiler | Port I2C3_SENS_SCL not matched to Sheet Entry at 160.02mm,121.92mm | 23:28:21 | 13/11/2025 | 51
[Error] | Sensor_IO_Buttons_LED.SchDoc | Compiler | Port I2C3_SENS_SDA not matched to Sheet Entry at 20.32mm,101.6mm | 23:28:21 | 13/11/2025 | 52
[Error] | MCU_RF.SchDoc | Compiler | Port I2C3_SENS_SDA not matched to Sheet Entry at 160.66mm,86.36mm | 23:28:21 | 13/11/2025 | 53
[Error] | Power_Charge_USB.SchDoc | Compiler | Port I2C_CHG_SCL not matched to Sheet Entry at 132.08mm,137.67mm | 23:28:21 | 13/11/2025 | 54
[Error] | MCU_RF.SchDoc | Compiler | Port I2C_CHG_SCL not matched to Sheet Entry at 217.81mm,81.28mm | 23:28:21 | 13/11/2025 | 55
[Error] | Power_Charge_USB.SchDoc | Compiler | Port I2C_CHG_SDA not matched to Sheet Entry at 132.08mm,140.21mm | 23:28:21 | 13/11/2025 | 56
[Error] | MCU_RF.SchDoc | Compiler | Port I2C_CHG_SDA not matched to Sheet Entry at 217.81mm,78.74mm | 23:28:21 | 13/11/2025 | 57
[Error] | Sensor_IO_Buttons_LED.SchDoc | Compiler | Port LED_STAT_N not matched to Sheet Entry at 21.59mm,35.56mm | 23:28:21 | 13/11/2025 | 58
[Error] | MCU_RF.SchDoc | Compiler | Port LED_STAT_N not matched to Sheet Entry at 160.66mm,96.52mm | 23:28:21 | 13/11/2025 | 59
[Error] | Sensor_IO_Buttons_LED.SchDoc | Compiler | Port SENS_EN not matched to Sheet Entry at 125.73mm,154.94mm | 23:28:21 | 13/11/2025 | 60
[Error] | MCU_RF.SchDoc | Compiler | Port SENS_EN not matched to Sheet Entry at 160.66mm,119.38mm | 23:28:21 | 13/11/2025 | 61
[Error] | MCU_RF.SchDoc | Compiler | Port TMP117_ALERT not matched to Sheet Entry at 160.02mm,134.62mm | 23:28:21 | 13/11/2025 | 62
[Error] | Sensor_IO_Buttons_LED.SchDoc | Compiler | Port TMP117_ALERT not matched to Sheet Entry at 163.83mm,152.4mm | 23:28:21 | 13/11/2025 | 63
[Error] | Power_Charge_USB.SchDoc | Compiler | Port USB_FS_R_N not matched to Sheet Entry at 174.75mm,77.47mm | 23:28:21 | 13/11/2025 | 64
[Error] | MCU_RF.SchDoc | Compiler | Port USB_FS_R_N not matched to Sheet Entry at 215.27mm,111.76mm | 23:28:21 | 13/11/2025 | 65
[Error] | Power_Charge_USB.SchDoc | Compiler | Port USB_FS_R_P not matched to Sheet Entry at 174.75mm,74.93mm | 23:28:21 | 13/11/2025 | 66
[Error] | MCU_RF.SchDoc | Compiler | Port USB_FS_R_P not matched to Sheet Entry at 215.9mm,109.22mm | 23:28:21 | 13/11/2025 | 67
[Warning] | Power_Charge_USB.SchDoc | Compiler | Net +3V3_SYS has no driving source (Pin C105-2, Pin C110-2, Pin IC1-D3, Pin IC1-D4, Pin IC1-E1, Pin R101-2, Pin R102-2, Pin R103-2) | 23:28:21 | 13/11/2025 | 68
[Warning] | Sensor_IO_Buttons_LED.SchDoc | Compiler | Net BMI270_INT1 has no driving source (Pin IC5-4, Pin R22-2) | 23:28:21 | 13/11/2025 | 69
[Warning] | Sensor_IO_Buttons_LED.SchDoc | Compiler | Net BMI270_INT2 has no driving source (Pin IC5-9, Pin R23-2) | 23:28:21 | 13/11/2025 | 70
[Warning] | Sensor_IO_Buttons_LED.SchDoc | Compiler | Net BTN1 has no driving source (Pin C29-2, Pin D3-1, Pin R21-1, Pin SW1-1) | 23:28:21 | 13/11/2025 | 71
[Warning] | MCU_RF.SchDoc | Compiler | Net CE_MCU has no driving source (Pin IC2-18) | 23:28:21 | 13/11/2025 | 72
[Warning] | MCU_RF.SchDoc | Compiler | Net LED_STAT_N has no driving source (Pin IC2-28) | 23:28:21 | 13/11/2025 | 73
[Warning] | MCU_RF.SchDoc | Compiler | Net SENS_EN has no driving source (Pin IC2-17) | 23:28:21 | 13/11/2025 | 74
[Warning] | Sensor_IO_Buttons_LED.SchDoc | Compiler | Net TMP117_ALERT has no driving source (Pin IC3-3, Pin R16-1) | 23:28:21 | 13/11/2025 | 75

Back to top

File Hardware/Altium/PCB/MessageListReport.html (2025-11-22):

Altium customize

# Message List

Date: | | 21/11/2025
Time: | | 11:30:12
Elapsed Time: | | 00:00:01

Class | Document | Source | Message | Time | Date | No.
[Clearance Constraint Violation] | BLE-Control.PcbDoc | Advanced PCB | Clearance Constraint: (0.096mm < 0.15mm) Between Pad IC3-1(120.559mm,21.28mm) on L1_TOP And Pad IC3-49(123.91mm,18.53mm) on L1_TOP | 11:28:34 | 21/11/2025 | 1
[Clearance Constraint Violation] | BLE-Control.PcbDoc | Advanced PCB | Clearance Constraint: (0.096mm < 0.15mm) Between Pad IC3-20(124.66mm,15.179mm) on L1_TOP And Pad IC3-49(123.91mm,18.53mm) on L1_TOP | 11:28:34 | 21/11/2025 | 2
[Clearance Constraint Violation] | BLE-Control.PcbDoc | Advanced PCB | Clearance Constraint: (0.096mm < 0.15mm) Between Pad IC3-23(126.16mm,15.179mm) on L1_TOP And Pad IC3-49(123.91mm,18.53mm) on L1_TOP | 11:28:34 | 21/11/2025 | 3
[Clearance Constraint Violation] | BLE-Control.PcbDoc | Advanced PCB | Clearance Constraint: (0.096mm < 0.15mm) Between Pad IC3-35(127.262mm,20.78mm) on L1_TOP And Pad IC3-49(123.91mm,18.53mm) on L1_TOP | 11:28:34 | 21/11/2025 | 4
[Clearance Constraint Violation] | BLE-Control.PcbDoc | Advanced PCB | Clearance Constraint: (0.096mm < 0.15mm) Between Pad IC3-40(125.16mm,21.881mm) on L1_TOP And Pad IC3-49(123.91mm,18.53mm) on L1_TOP | 11:28:34 | 21/11/2025 | 5
[Clearance Constraint Violation] | BLE-Control.PcbDoc | Advanced PCB | Clearance Constraint: (0.096mm < 0.15mm) Between Pad IC3-48(121.16mm,21.881mm) on L1_TOP And Pad IC3-49(123.91mm,18.53mm) on L1_TOP | 11:28:34 | 21/11/2025 | 6
[Clearance Constraint Violation] | BLE-Control.PcbDoc | Advanced PCB | Clearance Constraint: (0.096mm < 0.15mm) Between Pad IC3-49(123.91mm,18.53mm) on L1_TOP And Pad IC3-8(120.559mm,17.78mm) on L1_TOP | 11:28:34 | 21/11/2025 | 7
[Minimum Solder Mask Sliver Constraint Violation] | BLE-Control.PcbDoc | Advanced PCB | Minimum Solder Mask Sliver Constraint: (0.197mm < 0.254mm) Between Pad C10-1(120.735mm,2.544mm) on L1_TOP And Pad C10-2(120.735mm,3.544mm) on L1_TOP [Top Solder] Mask Sliver [0.197mm] | 11:28:34 | 21/11/2025 | 8
[Minimum Solder Mask Sliver Constraint Violation] | BLE-Control.PcbDoc | Advanced PCB | Minimum Solder Mask Sliver Constraint: (0.197mm < 0.254mm) Between Pad C101-1(29.75mm,21.25mm) on L1_TOP And Pad C101-2(30.75mm,21.25mm) on L1_TOP [Top Solder] Mask Sliver [0.197mm] | 11:28:34 | 21/11/2025 | 9
[Minimum Solder Mask Sliver Constraint Violation] | BLE-Control.PcbDoc | Advanced PCB | Minimum Solder Mask Sliver Constraint: (0.118mm < 0.254mm) Between Pad C101-1(29.75mm,21.25mm) on L1_TOP And Pad J2-2(29.25mm,20.18mm) on Multi-Layer [Top Solder] Mask Sliver [0.118mm] | 11:28:34 | 21/11/2025 | 10
[Minimum Solder Mask Sliver Constraint Violation] | BLE-Control.PcbDoc | Advanced PCB | Minimum Solder Mask Sliver Constraint: (0.197mm < 0.254mm) Between Pad C102-1(66.866mm,1.717mm) on L1_TOP And Pad C102-2(66.866mm,2.717mm) on L1_TOP [Top Solder] Mask Sliver [0.197mm] | 11:28:34 | 21/11/2025 | 11
[Minimum Solder Mask Sliver Constraint Violation] | BLE-Control.PcbDoc | Advanced PCB | Minimum Solder Mask Sliver Constraint: (0.197mm < 0.254mm) Between Pad C103-1(21.7mm,20.5mm) on L1_TOP And Pad C103-2(21.7mm,19.5mm) on L1_TOP [Top Solder] Mask Sliver [0.197mm] | 11:28:34 | 21/11/2025 | 12
[Minimum Solder Mask Sliver Constraint Violation] | BLE-Control.PcbDoc | Advanced PCB | Minimum Solder Mask Sliver Constraint: (0.197mm < 0.254mm) Between Pad C104-1(69.914mm,1.971mm) on L1_TOP And Pad C104-2(69.914mm,2.971mm) on L1_TOP [Top Solder] Mask Sliver [0.197mm] | 11:28:34 | 21/11/2025 | 13
[Minimum Solder Mask Sliver Constraint Violation] | BLE-Control.PcbDoc | Advanced PCB | Minimum Solder Mask Sliver Constraint: (0.197mm < 0.254mm) Between Pad C105-1(53.22mm,1.12mm) on L1_TOP And Pad C105-2(53.22mm,2.12mm) on L1_TOP [Top Solder] Mask Sliver [0.197mm] | 11:28:34 | 21/11/2025 | 14
[Minimum Solder Mask Sliver Constraint Violation] | BLE-Control.PcbDoc | Advanced PCB | Minimum Solder Mask Sliver Constraint: (0.197mm < 0.254mm) Between Pad C106-1(58.22mm,1.12mm) on L1_TOP And Pad C106-2(58.22mm,2.12mm) on L1_TOP [Top Solder] Mask Sliver [0.197mm] | 11:28:34 | 21/11/2025 | 15
[Minimum Solder Mask Sliver Constraint Violation] | BLE-Control.PcbDoc | Advanced PCB | Minimum Solder Mask Sliver Constraint: (0.197mm < 0.254mm) Between Pad C1-1(61.22mm,1.62mm) on L1_TOP And Pad C1-2(61.22mm,2.62mm) on L1_TOP [Top Solder] Mask Sliver [0.197mm] | 11:28:34 | 21/11/2025 | 16
[Minimum Solder Mask Sliver Constraint Violation] | BLE-Control.PcbDoc | Advanced PCB | Minimum Solder Mask Sliver Constraint: (0.197mm < 0.254mm) Between Pad C110-1(61.22mm,-4.88mm) on L1_TOP And Pad C110-2(61.22mm,-3.88mm) on L1_TOP [Top Solder] Mask Sliver [0.197mm] | 11:28:34 | 21/11/2025 | 17
[Minimum Solder Mask Sliver Constraint Violation] | BLE-Control.PcbDoc | Advanced PCB | Minimum Solder Mask Sliver Constraint: (0.197mm < 0.254mm) Between Pad C11-1(133.808mm,0.877mm) on L1_TOP And Pad C11-2(132.808mm,0.877mm) on L1_TOP [Top Solder] Mask Sliver [0.197mm] | 11:28:34 | 21/11/2025 | 18
[Minimum Solder Mask Sliver Constraint Violation] | BLE-Control.PcbDoc | Advanced PCB | Minimum Solder Mask Sliver Constraint: (0.197mm < 0.254mm) Between Pad C12-1(129.49mm,0.877mm) on L1_TOP And Pad C12-2(128.49mm,0.877mm) on L1_TOP [Top Solder] Mask Sliver [0.197mm] | 11:28:34 | 21/11/2025 | 19
[Minimum Solder Mask Sliver Constraint Violation] | BLE-Control.PcbDoc | Advanced PCB | Minimum Solder Mask Sliver Constraint: (0.197mm < 0.254mm) Between Pad C13-1(125.172mm,0.877mm) on L1_TOP And Pad C13-2(124.172mm,0.877mm) on L1_TOP [Top Solder] Mask Sliver [0.197mm] | 11:28:34 | 21/11/2025 | 20
[Minimum Solder Mask Sliver Constraint Violation] | BLE-Control.PcbDoc | Advanced PCB | Minimum Solder Mask Sliver Constraint: (0.197mm < 0.254mm) Between Pad C14-1(136.483mm,7.743mm) on L1_TOP And Pad C14-2(136.483mm,8.743mm) on L1_TOP [Top Solder] Mask Sliver [0.197mm] | 11:28:34 | 21/11/2025 | 21
[Minimum Solder Mask Sliver Constraint Violation] | BLE-Control.PcbDoc | Advanced PCB | Minimum Solder Mask Sliver Constraint: (0.197mm < 0.254mm) Between Pad C15-1(142.071mm,7.743mm) on L1_TOP And Pad C15-2(142.071mm,8.743mm) on L1_TOP [Top Solder] Mask Sliver [0.197mm] | 11:28:34 | 21/11/2025 | 22
[Minimum Solder Mask Sliver Constraint Violation] | BLE-Control.PcbDoc | Advanced PCB | Minimum Solder Mask Sliver Constraint: (0.197mm < 0.254mm) Between Pad C16-1(119.719mm,7.743mm) on L1_TOP And Pad C16-2(119.719mm,8.743mm) on L1_TOP [Top Solder] Mask Sliver [0.197mm] | 11:28:34 | 21/11/2025 | 23
[Minimum Solder Mask Sliver Constraint Violation] | BLE-Control.PcbDoc | Advanced PCB | Minimum Solder Mask Sliver Constraint: (0.197mm < 0.254mm) Between Pad C17-1(125.307mm,7.743mm) on L1_TOP And Pad C17-2(125.307mm,8.743mm) on L1_TOP [Top Solder] Mask Sliver [0.197mm] | 11:28:34 | 21/11/2025 | 24
[Minimum Solder Mask Sliver Constraint Violation] | BLE-Control.PcbDoc | Advanced PCB | Minimum Solder Mask Sliver Constraint: (0.197mm < 0.254mm) Between Pad C18-1(130.895mm,7.743mm) on L1_TOP And Pad C18-2(130.895mm,8.743mm) on L1_TOP [Top Solder] Mask Sliver [0.197mm] | 11:28:34 | 21/11/2025 | 25
[Minimum Solder Mask Sliver Constraint Violation] | BLE-Control.PcbDoc | Advanced PCB | Minimum Solder Mask Sliver Constraint: (0.197mm < 0.254mm) Between Pad C19-1(96.351mm,7.743mm) on L1_TOP And Pad C19-2(96.351mm,8.743mm) on L1_TOP [Top Solder] Mask Sliver [0.197mm] | 11:28:34 | 21/11/2025 | 26
[Minimum Solder Mask Sliver Constraint Violation] | BLE-Control.PcbDoc | Advanced PCB | Minimum Solder Mask Sliver Constraint: (0.197mm < 0.254mm) Between Pad C20-1(90.763mm,7.743mm) on L1_TOP And Pad C20-2(90.763mm,8.743mm) on L1_TOP [Top Solder] Mask Sliver [0.197mm] | 11:28:34 | 21/11/2025 | 27
[Minimum Solder Mask Sliver Constraint Violation] | BLE-Control.PcbDoc | Advanced PCB | Minimum Solder Mask Sliver Constraint: (0.197mm < 0.254mm) Between Pad C2-1(53.22mm,-5.38mm) on L1_TOP And Pad C2-2(53.22mm,-4.38mm) on L1_TOP [Top Solder] Mask Sliver [0.197mm] | 11:28:34 | 21/11/2025 | 28
[Minimum Solder Mask Sliver Constraint Violation] | BLE-Control.PcbDoc | Advanced PCB | Minimum Solder Mask Sliver Constraint: (0.197mm < 0.254mm) Between Pad C21-1(100.923mm,2.155mm) on L1_TOP And Pad C21-2(100.923mm,3.155mm) on L1_TOP [Top Solder] Mask Sliver [0.197mm] | 11:28:34 | 21/11/2025 | 29
[Minimum Solder Mask Sliver Constraint Violation] | BLE-Control.PcbDoc | Advanced PCB | Minimum Solder Mask Sliver Constraint: (0.197mm < 0.254mm) Between Pad C22-1(106.511mm,2.155mm) on L1_TOP And Pad C22-2(106.511mm,3.155mm) on L1_TOP [Top Solder] Mask Sliver [0.197mm] | 11:28:34 | 21/11/2025 | 30
[Minimum Solder Mask Sliver Constraint Violation] | BLE-Control.PcbDoc | Advanced PCB | Minimum Solder Mask Sliver Constraint: (0.197mm < 0.254mm) Between Pad C23-1(113.75mm,0.631mm) on L1_TOP And Pad C23-2(113.75mm,1.631mm) on L1_TOP [Top Solder] Mask Sliver [0.197mm] | 11:28:34 | 21/11/2025 | 31
[Minimum Solder Mask Sliver Constraint Violation] | BLE-Control.PcbDoc | Advanced PCB | Minimum Solder Mask Sliver Constraint: (0.197mm < 0.254mm) Between Pad C24-1(178.289mm,-1.175mm) on L1_TOP And Pad C24-2(178.289mm,-0.175mm) on L1_TOP [Top Solder] Mask Sliver [0.197mm] | 11:28:34 | 21/11/2025 | 32
[Minimum Solder Mask Sliver Constraint Violation] | BLE-Control.PcbDoc | Advanced PCB | Minimum Solder Mask Sliver Constraint: (0.197mm < 0.254mm) Between Pad C25-1(171.812mm,5.04mm) on L1_TOP And Pad C25-2(171.812mm,6.04mm) on L1_TOP [Top Solder] Mask Sliver [0.197mm] | 11:28:34 | 21/11/2025 | 33
[Minimum Solder Mask Sliver Constraint Violation] | BLE-Control.PcbDoc | Advanced PCB | Minimum Solder Mask Sliver Constraint: (0.197mm < 0.254mm) Between Pad C26-1(202.673mm,0.222mm) on L1_TOP And Pad C26-2(202.673mm,1.222mm) on L1_TOP [Top Solder] Mask Sliver [0.197mm] | 11:28:34 | 21/11/2025 | 34
[Minimum Solder Mask Sliver Constraint Violation] | BLE-Control.PcbDoc | Advanced PCB | Minimum Solder Mask Sliver Constraint: (0.197mm < 0.254mm) Between Pad C27-1(194.037mm,5.421mm) on L1_TOP And Pad C27-2(194.037mm,6.421mm) on L1_TOP [Top Solder] Mask Sliver [0.197mm] | 11:28:34 | 21/11/2025 | 35
[Minimum Solder Mask Sliver Constraint Violation] | BLE-Control.PcbDoc | Advanced PCB | Minimum Solder Mask Sliver Constraint: (0.197mm < 0.254mm) Between Pad C28-1(187.56mm,-2.064mm) on L1_TOP And Pad C28-2(187.56mm,-1.064mm) on L1_TOP [Top Solder] Mask Sliver [0.197mm] | 11:28:34 | 21/11/2025 | 36
[Minimum Solder Mask Sliver Constraint Violation] | BLE-Control.PcbDoc | Advanced PCB | Minimum Solder Mask Sliver Constraint: (0.197mm < 0.254mm) Between Pad C29-1(182.099mm,-2.072mm) on L1_TOP And Pad C29-2(182.099mm,-1.072mm) on L1_TOP [Top Solder] Mask Sliver [0.197mm] | 11:28:34 | 21/11/2025 | 37
[Minimum Solder Mask Sliver Constraint Violation] | BLE-Control.PcbDoc | Advanced PCB | Minimum Solder Mask Sliver Constraint: (0.197mm < 0.254mm) Between Pad C3-1(57.22mm,-5.88mm) on L1_TOP And Pad C3-2(57.22mm,-4.88mm) on L1_TOP [Top Solder] Mask Sliver [0.197mm] | 11:28:34 | 21/11/2025 | 38
[Minimum Solder Mask Sliver Constraint Violation] | BLE-Control.PcbDoc | Advanced PCB | Minimum Solder Mask Sliver Constraint: (0.197mm < 0.254mm) Between Pad C8-1(151.596mm,1.393mm) on L1_TOP And Pad C8-2(151.596mm,2.393mm) on L1_TOP [Top Solder] Mask Sliver [0.197mm] | 11:28:34 | 21/11/2025 | 39
[Minimum Solder Mask Sliver Constraint Violation] | BLE-Control.PcbDoc | Advanced PCB | Minimum Solder Mask Sliver Constraint: (0.197mm < 0.254mm) Between Pad C9-1(118.449mm,2.663mm) on L1_TOP And Pad C9-2(118.449mm,3.663mm) on L1_TOP [Top Solder] Mask Sliver [0.197mm] | 11:28:34 | 21/11/2025 | 40
[Minimum Solder Mask Sliver Constraint Violation] | BLE-Control.PcbDoc | Advanced PCB | Minimum Solder Mask Sliver Constraint: (0.047mm < 0.254mm) Between Pad D101-1(27mm,18.125mm) on L1_TOP And Pad R1-1(27.3mm,16.9mm) on L1_TOP [Top Solder] Mask Sliver [0.047mm] | 11:28:34 | 21/11/2025 | 41
[Minimum Solder Mask Sliver Constraint Violation] | BLE-Control.PcbDoc | Advanced PCB | Minimum Solder Mask Sliver Constraint: (0.047mm < 0.254mm) Between Pad D101-1(27mm,18.125mm) on L1_TOP And Pad R1-2(26.3mm,16.9mm) on L1_TOP [Top Solder] Mask Sliver [0.047mm] | 11:28:34 | 21/11/2025 | 42
[Minimum Solder Mask Sliver Constraint Violation] | BLE-Control.PcbDoc | Advanced PCB | Minimum Solder Mask Sliver Constraint: (0.147mm < 0.254mm) Between Pad D102-1(26.75mm,13.05mm) on L1_TOP And Pad D102-2(26.75mm,14mm) on L1_TOP [Top Solder] Mask Sliver [0.147mm] | 11:28:34 | 21/11/2025 | 43
[Minimum Solder Mask Sliver Constraint Violation] | BLE-Control.PcbDoc | Advanced PCB | Minimum Solder Mask Sliver Constraint: (0.197mm < 0.254mm) Between Pad D102-1(26.75mm,13.05mm) on L1_TOP And Pad ESD_CC1-1(26.85mm,12mm) on L1_TOP [Top Solder] Mask Sliver [0.197mm] | 11:28:34 | 21/11/2025 | 44
[Minimum Solder Mask Sliver Constraint Violation] | BLE-Control.PcbDoc | Advanced PCB | Minimum Solder Mask Sliver Constraint: (0.197mm < 0.254mm) Between Pad D102-1(26.75mm,13.05mm) on L1_TOP And Pad ESD_CC1-2(26.15mm,12mm) on L1_TOP [Top Solder] Mask Sliver [0.197mm] | 11:28:34 | 21/11/2025 | 45
[Minimum Solder Mask Sliver Constraint Violation] | BLE-Control.PcbDoc | Advanced PCB | Minimum Solder Mask Sliver Constraint: (0.147mm < 0.254mm) Between Pad D102-2(26.75mm,14mm) on L1_TOP And Pad D102-3(26.75mm,14.95mm) on L1_TOP [Top Solder] Mask Sliver [0.147mm] | 11:28:34 | 21/11/2025 | 46
[Minimum Solder Mask Sliver Constraint Violation] | BLE-Control.PcbDoc | Advanced PCB | Minimum Solder Mask Sliver Constraint: (0.197mm < 0.254mm) Between Pad D102-3(26.75mm,14.95mm) on L1_TOP And Pad ESD_CC2-1(27.1mm,16mm) on L1_TOP [Top Solder] Mask Sliver [0.197mm] | 11:28:34 | 21/11/2025 | 47
[Minimum Solder Mask Sliver Constraint Violation] | BLE-Control.PcbDoc | Advanced PCB | Minimum Solder Mask Sliver Constraint: (0.197mm < 0.254mm) Between Pad D102-3(26.75mm,14.95mm) on L1_TOP And Pad ESD_CC2-2(26.4mm,16mm) on L1_TOP [Top Solder] Mask Sliver [0.197mm] | 11:28:34 | 21/11/2025 | 48
[Minimum Solder Mask Sliver Constraint Violation] | BLE-Control.PcbDoc | Advanced PCB | Minimum Solder Mask Sliver Constraint: (0.147mm < 0.254mm) Between Pad D102-4(24.25mm,14.95mm) on L1_TOP And Pad D102-5(24.25mm,14mm) on L1_TOP [Top Solder] Mask Sliver [0.147mm] | 11:28:34 | 21/11/2025 | 49
[Minimum Solder Mask Sliver Constraint Violation] | BLE-Control.PcbDoc | Advanced PCB | Minimum Solder Mask Sliver Constraint: (0.147mm < 0.254mm) Between Pad D102-5(24.25mm,14mm) on L1_TOP And Pad D102-6(24.25mm,13.05mm) on L1_TOP [Top Solder] Mask Sliver [0.147mm] | 11:28:34 | 21/11/2025 | 50
[Minimum Solder Mask Sliver Constraint Violation] | BLE-Control.PcbDoc | Advanced PCB | Minimum Solder Mask Sliver Constraint: (0.197mm < 0.254mm) Between Pad D102-6(24.25mm,13.05mm) on L1_TOP And Pad R104-1(25mm,12mm) on L1_TOP [Top Solder] Mask Sliver [0.197mm] | 11:28:34 | 21/11/2025 | 51
[Minimum Solder Mask Sliver Constraint Violation] | BLE-Control.PcbDoc | Advanced PCB | Minimum Solder Mask Sliver Constraint: (0.197mm < 0.254mm) Between Pad D102-6(24.25mm,13.05mm) on L1_TOP And Pad R104-2(24mm,12mm) on L1_TOP [Top Solder] Mask Sliver [0.197mm] | 11:28:34 | 21/11/2025 | 52
[Minimum Solder Mask Sliver Constraint Violation] | BLE-Control.PcbDoc | Advanced PCB | Minimum Solder Mask Sliver Constraint: (0.097mm < 0.254mm) Between Pad D3-1(200.387mm,12.906mm) on L1_TOP And Pad D3-2(200.387mm,13.606mm) on L1_TOP [Top Solder] Mask Sliver [0.097mm] | 11:28:34 | 21/11/2025 | 53
[Minimum Solder Mask Sliver Constraint Violation] | BLE-Control.PcbDoc | Advanced PCB | Minimum Solder Mask Sliver Constraint: (0.097mm < 0.254mm) Between Pad ESD_CC1-1(26.85mm,12mm) on L1_TOP And Pad ESD_CC1-2(26.15mm,12mm) on L1_TOP [Top Solder] Mask Sliver [0.097mm] | 11:28:34 | 21/11/2025 | 54
[Minimum Solder Mask Sliver Constraint Violation] | BLE-Control.PcbDoc | Advanced PCB | Minimum Solder Mask Sliver Constraint: (0.097mm < 0.254mm) Between Pad ESD_CC2-1(27.1mm,16mm) on L1_TOP And Pad ESD_CC2-2(26.4mm,16mm) on L1_TOP [Top Solder] Mask Sliver [0.097mm] | 11:28:34 | 21/11/2025 | 55
[Minimum Solder Mask Sliver Constraint Violation] | BLE-Control.PcbDoc | Advanced PCB | Minimum Solder Mask Sliver Constraint: (0.147mm < 0.254mm) Between Pad ESD_CC2-1(27.1mm,16mm) on L1_TOP And Pad R1-2(26.3mm,16.9mm) on L1_TOP [Top Solder] Mask Sliver [0.147mm] | 11:28:34 | 21/11/2025 | 56
[Minimum Solder Mask Sliver Constraint Violation] | BLE-Control.PcbDoc | Advanced PCB | Minimum Solder Mask Sliver Constraint: (0.235mm < 0.254mm) Between Pad ESD_CC2-2(26.4mm,16mm) on L1_TOP And Pad R1-1(27.3mm,16.9mm) on L1_TOP [Top Solder] Mask Sliver [0.235mm] | 11:28:34 | 21/11/2025 | 57
[Minimum Solder Mask Sliver Constraint Violation] | BLE-Control.PcbDoc | Advanced PCB | Minimum Solder Mask Sliver Constraint: (0.097mm < 0.254mm) Between Pad ESD_RF1-1(147.786mm,8.02mm) on L1_TOP And Pad ESD_RF1-2(147.786mm,8.72mm) on L1_TOP [Top Solder] Mask Sliver [0.097mm] | 11:28:34 | 21/11/2025 | 58
[Minimum Solder Mask Sliver Constraint Violation] | BLE-Control.PcbDoc | Advanced PCB | Minimum Solder Mask Sliver Constraint: (0.242mm < 0.254mm) Between Pad FB101-1(23.1mm,20.479mm) on L1_TOP And Pad FB101-2(23.1mm,19.521mm) on L1_TOP [Top Solder] Mask Sliver [0.242mm] | 11:28:34 | 21/11/2025 | 59
[Minimum Solder Mask Sliver Constraint Violation] | BLE-Control.PcbDoc | Advanced PCB | Minimum Solder Mask Sliver Constraint: (0.242mm < 0.254mm) Between Pad FB2-1(186.798mm,19.764mm) on L1_TOP And Pad FB2-2(186.798mm,20.721mm) on L1_TOP [Top Solder] Mask Sliver [0.242mm] | 11:28:34 | 21/11/2025 | 60
[Minimum Solder Mask Sliver Constraint Violation] | BLE-Control.PcbDoc | Advanced PCB | Minimum Solder Mask Sliver Constraint: (0.197mm < 0.254mm) Between Pad FL101-1(22.425mm,13.5mm) on L1_TOP And Pad FL101-2(22.425mm,14.3mm) on L1_TOP [Top Solder] Mask Sliver [0.197mm] | 11:28:34 | 21/11/2025 | 61
[Minimum Solder Mask Sliver Constraint Violation] | BLE-Control.PcbDoc | Advanced PCB | Minimum Solder Mask Sliver Constraint: (0.197mm < 0.254mm) Between Pad FL101-3(20.575mm,14.3mm) on L1_TOP And Pad FL101-4(20.575mm,13.5mm) on L1_TOP [Top Solder] Mask Sliver [0.197mm] | 11:28:34 | 21/11/2025 | 62
[Minimum Solder Mask Sliver Constraint Violation] | BLE-Control.PcbDoc | Advanced PCB | Minimum Solder Mask Sliver Constraint: (0.046mm < 0.254mm) Between Pad FL2-1(142.221mm,1.004mm) on L1_TOP And Pad FL2-2(142.833mm,0.777mm) on L1_TOP [Top Solder] Mask Sliver [0.046mm] | 11:28:34 | 21/11/2025 | 63
[Minimum Solder Mask Sliver Constraint Violation] | BLE-Control.PcbDoc | Advanced PCB | Minimum Solder Mask Sliver Constraint: (0.046mm < 0.254mm) Between Pad FL2-1(142.221mm,1.004mm) on L1_TOP And Pad FL2-4(142.833mm,1.231mm) on L1_TOP [Top Solder] Mask Sliver [0.046mm] | 11:28:34 | 21/11/2025 | 64
[Minimum Solder Mask Sliver Constraint Violation] | BLE-Control.PcbDoc | Advanced PCB | Minimum Solder Mask Sliver Constraint: (0.047mm < 0.254mm) Between Pad FL2-2(142.833mm,0.777mm) on L1_TOP And Pad FL2-3(143.446mm,1.004mm) on L1_TOP [Top Solder] Mask Sliver [0.047mm] | 11:28:34 | 21/11/2025 | 65
[Minimum Solder Mask Sliver Constraint Violation] | BLE-Control.PcbDoc | Advanced PCB | Minimum Solder Mask Sliver Constraint: (0.006mm < 0.254mm) Between Pad FL2-2(142.833mm,0.777mm) on L1_TOP And Pad FL2-4(142.833mm,1.231mm) on L1_TOP [Top Solder] Mask Sliver [0.006mm] | 11:28:34 | 21/11/2025 | 66
[Minimum Solder Mask Sliver Constraint Violation] | BLE-Control.PcbDoc | Advanced PCB | Minimum Solder Mask Sliver Constraint: (0.047mm < 0.254mm) Between Pad FL2-3(143.446mm,1.004mm) on L1_TOP And Pad FL2-4(142.833mm,1.231mm) on L1_TOP [Top Solder] Mask Sliver [0.047mm] | 11:28:34 | 21/11/2025 | 67
[Minimum Solder Mask Sliver Constraint Violation] | BLE-Control.PcbDoc | Advanced PCB | Minimum Solder Mask Sliver Constraint: (0.136mm < 0.254mm) Between Pad IC1-A1(21.7mm,8.2mm) on L1_TOP And Pad IC1-B2(22.1mm,7.8mm) on L1_TOP [Top Solder] Mask Sliver [0.136mm] | 11:28:34 | 21/11/2025 | 68
[Minimum Solder Mask Sliver Constraint Violation] | BLE-Control.PcbDoc | Advanced PCB | Minimum Solder Mask Sliver Constraint: (0.136mm < 0.254mm) Between Pad IC1-A2(22.1mm,8.2mm) on L1_TOP And Pad IC1-B1(21.7mm,7.8mm) on L1_TOP [Top Solder] Mask Sliver [0.136mm] | 11:28:34 | 21/11/2025 | 69
[Minimum Solder Mask Sliver Constraint Violation] | BLE-Control.PcbDoc | Advanced PCB | Minimum Solder Mask Sliver Constraint: (0.136mm < 0.254mm) Between Pad IC1-A2(22.1mm,8.2mm) on L1_TOP And Pad IC1-B3(22.5mm,7.8mm) on L1_TOP [Top Solder] Mask Sliver [0.136mm] | 11:28:34 | 21/11/2025 | 70
[Minimum Solder Mask Sliver Constraint Violation] | BLE-Control.PcbDoc | Advanced PCB | Minimum Solder Mask Sliver Constraint: (0.136mm < 0.254mm) Between Pad IC1-A3(22.5mm,8.2mm) on L1_TOP And Pad IC1-B2(22.1mm,7.8mm) on L1_TOP [Top Solder] Mask Sliver [0.136mm] | 11:28:34 | 21/11/2025 | 71
[Minimum Solder Mask Sliver Constraint Violation] | BLE-Control.PcbDoc | Advanced PCB | Minimum Solder Mask Sliver Constraint: (0.136mm < 0.254mm) Between Pad IC1-A3(22.5mm,8.2mm) on L1_TOP And Pad IC1-B4(22.9mm,7.8mm) on L1_TOP [Top Solder] Mask Sliver [0.136mm] | 11:28:34 | 21/11/2025 | 72
[Minimum Solder Mask Sliver Constraint Violation] | BLE-Control.PcbDoc | Advanced PCB | Minimum Solder Mask Sliver Constraint: (0.136mm < 0.254mm) Between Pad IC1-A4(22.9mm,8.2mm) on L1_TOP And Pad IC1-B3(22.5mm,7.8mm) on L1_TOP [Top Solder] Mask Sliver [0.136mm] | 11:28:34 | 21/11/2025 | 73
[Minimum Solder Mask Sliver Constraint Violation] | BLE-Control.PcbDoc | Advanced PCB | Minimum Solder Mask Sliver Constraint: (0.136mm < 0.254mm) Between Pad IC1-B1(21.7mm,7.8mm) on L1_TOP And Pad IC1-C2(22.1mm,7.4mm) on L1_TOP [Top Solder] Mask Sliver [0.136mm] | 11:28:34 | 21/11/2025 | 74
[Minimum Solder Mask Sliver Constraint Violation] | BLE-Control.PcbDoc | Advanced PCB | Minimum Solder Mask Sliver Constraint: (0.136mm < 0.254mm) Between Pad IC1-B2(22.1mm,7.8mm) on L1_TOP And Pad IC1-C1(21.7mm,7.4mm) on L1_TOP [Top Solder] Mask Sliver [0.136mm] | 11:28:34 | 21/11/2025 | 75
[Minimum Solder Mask Sliver Constraint Violation] | BLE-Control.PcbDoc | Advanced PCB | Minimum Solder Mask Sliver Constraint: (0.136mm < 0.254mm) Between Pad IC1-B2(22.1mm,7.8mm) on L1_TOP And Pad IC1-C3(22.5mm,7.4mm) on L1_TOP [Top Solder] Mask Sliver [0.136mm] | 11:28:34 | 21/11/2025 | 76
[Minimum Solder Mask Sliver Constraint Violation] | BLE-Control.PcbDoc | Advanced PCB | Minimum Solder Mask Sliver Constraint: (0.136mm < 0.254mm) Between Pad IC1-B3(22.5mm,7.8mm) on L1_TOP And Pad IC1-C2(22.1mm,7.4mm) on L1_TOP [Top Solder] Mask Sliver [0.136mm] | 11:28:34 | 21/11/2025 | 77
[Minimum Solder Mask Sliver Constraint Violation] | BLE-Control.PcbDoc | Advanced PCB | Minimum Solder Mask Sliver Constraint: (0.136mm < 0.254mm) Between Pad IC1-B3(22.5mm,7.8mm) on L1_TOP And Pad IC1-C4(22.9mm,7.4mm) on L1_TOP [Top Solder] Mask Sliver [0.136mm] | 11:28:34 | 21/11/2025 | 78
[Minimum Solder Mask Sliver Constraint Violation] | BLE-Control.PcbDoc | Advanced PCB | Minimum Solder Mask Sliver Constraint: (0.136mm < 0.254mm) Between Pad IC1-B4(22.9mm,7.8mm) on L1_TOP And Pad IC1-C3(22.5mm,7.4mm) on L1_TOP [Top Solder] Mask Sliver [0.136mm] | 11:28:34 | 21/11/2025 | 79
[Minimum Solder Mask Sliver Constraint Violation] | BLE-Control.PcbDoc | Advanced PCB | Minimum Solder Mask Sliver Constraint: (0.136mm < 0.254mm) Between Pad IC1-C1(21.7mm,7.4mm) on L1_TOP And Pad IC1-D2(22.1mm,7mm) on L1_TOP [Top Solder] Mask Sliver [0.136mm] | 11:28:34 | 21/11/2025 | 80
[Minimum Solder Mask Sliver Constraint Violation] | BLE-Control.PcbDoc | Advanced PCB | Minimum Solder Mask Sliver Constraint: (0.136mm < 0.254mm) Between Pad IC1-C2(22.1mm,7.4mm) on L1_TOP And Pad IC1-D1(21.7mm,7mm) on L1_TOP [Top Solder] Mask Sliver [0.136mm] | 11:28:34 | 21/11/2025 | 81
[Minimum Solder Mask Sliver Constraint Violation] | BLE-Control.PcbDoc | Advanced PCB | Minimum Solder Mask Sliver Constraint: (0.136mm < 0.254mm) Between Pad IC1-C2(22.1mm,7.4mm) on L1_TOP And Pad IC1-D3(22.5mm,7mm) on L1_TOP [Top Solder] Mask Sliver [0.136mm] | 11:28:34 | 21/11/2025 | 82
[Minimum Solder Mask Sliver Constraint Violation] | BLE-Control.PcbDoc | Advanced PCB | Minimum Solder Mask Sliver Constraint: (0.136mm < 0.254mm) Between Pad IC1-C3(22.5mm,7.4mm) on L1_TOP And Pad IC1-D2(22.1mm,7mm) on L1_TOP [Top Solder] Mask Sliver [0.136mm] | 11:28:34 | 21/11/2025 | 83
[Minimum Solder Mask Sliver Constraint Violation] | BLE-Control.PcbDoc | Advanced PCB | Minimum Solder Mask Sliver Constraint: (0.136mm < 0.254mm) Between Pad IC1-C3(22.5mm,7.4mm) on L1_TOP And Pad IC1-D4(22.9mm,7mm) on L1_TOP [Top Solder] Mask Sliver [0.136mm] | 11:28:34 | 21/11/2025 | 84
[Minimum Solder Mask Sliver Constraint Violation] | BLE-Control.PcbDoc | Advanced PCB | Minimum Solder Mask Sliver Constraint: (0.136mm < 0.254mm) Between Pad IC1-C4(22.9mm,7.4mm) on L1_TOP And Pad IC1-D3(22.5mm,7mm) on L1_TOP [Top Solder] Mask Sliver [0.136mm] | 11:28:34 | 21/11/2025 | 85
[Minimum Solder Mask Sliver Constraint Violation] | BLE-Control.PcbDoc | Advanced PCB | Minimum Solder Mask Sliver Constraint: (0.136mm < 0.254mm) Between Pad IC1-D1(21.7mm,7mm) on L1_TOP And Pad IC1-E2(22.1mm,6.6mm) on L1_TOP [Top Solder] Mask Sliver [0.136mm] | 11:28:34 | 21/11/2025 | 86
[Minimum Solder Mask Sliver Constraint Violation] | BLE-Control.PcbDoc | Advanced PCB | Minimum Solder Mask Sliver Constraint: (0.136mm < 0.254mm) Between Pad IC1-D2(22.1mm,7mm) on L1_TOP And Pad IC1-E1(21.7mm,6.6mm) on L1_TOP [Top Solder] Mask Sliver [0.136mm] | 11:28:34 | 21/11/2025 | 87
[Minimum Solder Mask Sliver Constraint Violation] | BLE-Control.PcbDoc | Advanced PCB | Minimum Solder Mask Sliver Constraint: (0.136mm < 0.254mm) Between Pad IC1-D2(22.1mm,7mm) on L1_TOP And Pad IC1-E3(22.5mm,6.6mm) on L1_TOP [Top Solder] Mask Sliver [0.136mm] | 11:28:34 | 21/11/2025 | 88
[Minimum Solder Mask Sliver Constraint Violation] | BLE-Control.PcbDoc | Advanced PCB | Minimum Solder Mask Sliver Constraint: (0.136mm < 0.254mm) Between Pad IC1-D3(22.5mm,7mm) on L1_TOP And Pad IC1-E2(22.1mm,6.6mm) on L1_TOP [Top Solder] Mask Sliver [0.136mm] | 11:28:34 | 21/11/2025 | 89
[Minimum Solder Mask Sliver Constraint Violation] | BLE-Control.PcbDoc | Advanced PCB | Minimum Solder Mask Sliver Constraint: (0.136mm < 0.254mm) Between Pad IC1-D3(22.5mm,7mm) on L1_TOP And Pad IC1-E4(22.9mm,6.6mm) on L1_TOP [Top Solder] Mask Sliver [0.136mm] | 11:28:34 | 21/11/2025 | 90
[Minimum Solder Mask Sliver Constraint Violation] | BLE-Control.PcbDoc | Advanced PCB | Minimum Solder Mask Sliver Constraint: (0.136mm < 0.254mm) Between Pad IC1-D4(22.9mm,7mm) on L1_TOP And Pad IC1-E3(22.5mm,6.6mm) on L1_TOP [Top Solder] Mask Sliver [0.136mm] | 11:28:34 | 21/11/2025 | 91
[Minimum Solder Mask Sliver Constraint Violation] | BLE-Control.PcbDoc | Advanced PCB | Minimum Solder Mask Sliver Constraint: (0.157mm < 0.254mm) Between Pad IC3-1(120.559mm,21.28mm) on L1_TOP And Pad IC3-48(121.16mm,21.881mm) on L1_TOP [Top Solder] Mask Sliver [0.157mm] | 11:28:34 | 21/11/2025 | 92
[Minimum Solder Mask Sliver Constraint Violation] | BLE-Control.PcbDoc | Advanced PCB | Minimum Solder Mask Sliver Constraint: (0.096mm < 0.254mm) Between Pad IC3-1(120.559mm,21.28mm) on L1_TOP And Pad IC3-49(123.91mm,18.53mm) on L1_TOP [Top Solder] Mask Sliver [0.096mm] | 11:28:34 | 21/11/2025 | 93
[Minimum Solder Mask Sliver Constraint Violation] | BLE-Control.PcbDoc | Advanced PCB | Minimum Solder Mask Sliver Constraint: (0.096mm < 0.254mm) Between Pad IC3-10(120.559mm,16.78mm) on L1_TOP And Pad IC3-49(123.91mm,18.53mm) on L1_TOP [Top Solder] Mask Sliver [0.096mm] | 11:28:34 | 21/11/2025 | 94
[Minimum Solder Mask Sliver Constraint Violation] | BLE-Control.PcbDoc | Advanced PCB | Minimum Solder Mask Sliver Constraint: (0.096mm < 0.254mm) Between Pad IC3-11(120.559mm,16.28mm) on L1_TOP And Pad IC3-49(123.91mm,18.53mm) on L1_TOP [Top Solder] Mask Sliver [0.096mm] | 11:28:34 | 21/11/2025 | 95
[Minimum Solder Mask Sliver Constraint Violation] | BLE-Control.PcbDoc | Advanced PCB | Minimum Solder Mask Sliver Constraint: (0.207mm < 0.254mm) Between Pad IC3-12(120.559mm,15.78mm) on L1_TOP And Pad IC3-13(121.16mm,15.179mm) on L1_TOP [Top Solder] Mask Sliver [0.207mm] | 11:28:34 | 21/11/2025 | 96
[Minimum Solder Mask Sliver Constraint Violation] | BLE-Control.PcbDoc | Advanced PCB | Minimum Solder Mask Sliver Constraint: (0.096mm < 0.254mm) Between Pad IC3-12(120.559mm,15.78mm) on L1_TOP And Pad IC3-49(123.91mm,18.53mm) on L1_TOP [Top Solder] Mask Sliver [0.096mm] | 11:28:34 | 21/11/2025 | 97
[Minimum Solder Mask Sliver Constraint Violation] | BLE-Control.PcbDoc | Advanced PCB | Minimum Solder Mask Sliver Constraint: (0.096mm < 0.254mm) Between Pad IC3-13(121.16mm,15.179mm) on L1_TOP And Pad IC3-49(123.91mm,18.53mm) on L1_TOP [Top Solder] Mask Sliver [0.096mm] | 11:28:34 | 21/11/2025 | 98
[Minimum Solder Mask Sliver Constraint Violation] | BLE-Control.PcbDoc | Advanced PCB | Minimum Solder Mask Sliver Constraint: (0.096mm < 0.254mm) Between Pad IC3-14(121.66mm,15.179mm) on L1_TOP And Pad IC3-49(123.91mm,18.53mm) on L1_TOP [Top Solder] Mask Sliver [0.096mm] | 11:28:34 | 21/11/2025 | 99
[Minimum Solder Mask Sliver Constraint Violation] | BLE-Control.PcbDoc | Advanced PCB | Minimum Solder Mask Sliver Constraint: (0.096mm < 0.254mm) Between Pad IC3-15(122.16mm,15.179mm) on L1_TOP And Pad IC3-49(123.91mm,18.53mm) on L1_TOP [Top Solder] Mask Sliver [0.096mm] | 11:28:34 | 21/11/2025 | 100
[Minimum Solder Mask Sliver Constraint Violation] | BLE-Control.PcbDoc | Advanced PCB | Minimum Solder Mask Sliver Constraint: (0.096mm < 0.254mm) Between Pad IC3-16(122.66mm,15.179mm) on L1_TOP And Pad IC3-49(123.91mm,18.53mm) on L1_TOP [Top Solder] Mask Sliver [0.096mm] | 11:28:34 | 21/11/2025 | 101
[Minimum Solder Mask Sliver Constraint Violation] | BLE-Control.PcbDoc | Advanced PCB | Minimum Solder Mask Sliver Constraint: (0.096mm < 0.254mm) Between Pad IC3-17(123.16mm,15.179mm) on L1_TOP And Pad IC3-49(123.91mm,18.53mm) on L1_TOP [Top Solder] Mask Sliver [0.096mm] | 11:28:34 | 21/11/2025 | 102
[Minimum Solder Mask Sliver Constraint Violation] | BLE-Control.PcbDoc | Advanced PCB | Minimum Solder Mask Sliver Constraint: (0.096mm < 0.254mm) Between Pad IC3-18(123.66mm,15.179mm) on L1_TOP And Pad IC3-49(123.91mm,18.53mm) on L1_TOP [Top Solder] Mask Sliver [0.096mm] | 11:28:34 | 21/11/2025 | 103
[Minimum Solder Mask Sliver Constraint Violation] | BLE-Control.PcbDoc | Advanced PCB | Minimum Solder Mask Sliver Constraint: (0.096mm < 0.254mm) Between Pad IC3-19(124.16mm,15.179mm) on L1_TOP And Pad IC3-49(123.91mm,18.53mm) on L1_TOP [Top Solder] Mask Sliver [0.096mm] | 11:28:34 | 21/11/2025 | 104
[Minimum Solder Mask Sliver Constraint Violation] | BLE-Control.PcbDoc | Advanced PCB | Minimum Solder Mask Sliver Constraint: (0.096mm < 0.254mm) Between Pad IC3-2(120.559mm,20.78mm) on L1_TOP And Pad IC3-49(123.91mm,18.53mm) on L1_TOP [Top Solder] Mask Sliver [0.096mm] | 11:28:34 | 21/11/2025 | 105
[Minimum Solder Mask Sliver Constraint Violation] | BLE-Control.PcbDoc | Advanced PCB | Minimum Solder Mask Sliver Constraint: (0.096mm < 0.254mm) Between Pad IC3-20(124.66mm,15.179mm) on L1_TOP And Pad IC3-49(123.91mm,18.53mm) on L1_TOP [Top Solder] Mask Sliver [0.096mm] | 11:28:34 | 21/11/2025 | 106
[Minimum Solder Mask Sliver Constraint Violation] | BLE-Control.PcbDoc | Advanced PCB | Minimum Solder Mask Sliver Constraint: (0.096mm < 0.254mm) Between Pad IC3-21(125.16mm,15.179mm) on L1_TOP And Pad IC3-49(123.91mm,18.53mm) on L1_TOP [Top Solder] Mask Sliver [0.096mm] | 11:28:34 | 21/11/2025 | 107
[Minimum Solder Mask Sliver Constraint Violation] | BLE-Control.PcbDoc | Advanced PCB | Minimum Solder Mask Sliver Constraint: (0.096mm < 0.254mm) Between Pad IC3-22(125.66mm,15.179mm) on L1_TOP And Pad IC3-49(123.91mm,18.53mm) on L1_TOP [Top Solder] Mask Sliver [0.096mm] | 11:28:34 | 21/11/2025 | 108
[Minimum Solder Mask Sliver Constraint Violation] | BLE-Control.PcbDoc | Advanced PCB | Minimum Solder Mask Sliver Constraint: (0.096mm < 0.254mm) Between Pad IC3-23(126.16mm,15.179mm) on L1_TOP And Pad IC3-49(123.91mm,18.53mm) on L1_TOP [Top Solder] Mask Sliver [0.096mm] | 11:28:34 | 21/11/2025 | 109
[Minimum Solder Mask Sliver Constraint Violation] | BLE-Control.PcbDoc | Advanced PCB | Minimum Solder Mask Sliver Constraint: (0.207mm < 0.254mm) Between Pad IC3-24(126.66mm,15.179mm) on L1_TOP And Pad IC3-25(127.262mm,15.78mm) on L1_TOP [Top Solder] Mask Sliver [0.207mm] | 11:28:34 | 21/11/2025 | 110
[Minimum Solder Mask Sliver Constraint Violation] | BLE-Control.PcbDoc | Advanced PCB | Minimum Solder Mask Sliver Constraint: (0.096mm < 0.254mm) Between Pad IC3-24(126.66mm,15.179mm) on L1_TOP And Pad IC3-49(123.91mm,18.53mm) on L1_TOP [Top Solder] Mask Sliver [0.096mm] | 11:28:34 | 21/11/2025 | 111
[Minimum Solder Mask Sliver Constraint Violation] | BLE-Control.PcbDoc | Advanced PCB | Minimum Solder Mask Sliver Constraint: (0.096mm < 0.254mm) Between Pad IC3-25(127.262mm,15.78mm) on L1_TOP And Pad IC3-49(123.91mm,18.53mm) on L1_TOP [Top Solder] Mask Sliver [0.096mm] | 11:28:34 | 21/11/2025 | 112
[Minimum Solder Mask Sliver Constraint Violation] | BLE-Control.PcbDoc | Advanced PCB | Minimum Solder Mask Sliver Constraint: (0.096mm < 0.254mm) Between Pad IC3-26(127.262mm,16.28mm) on L1_TOP And Pad IC3-49(123.91mm,18.53mm) on L1_TOP [Top Solder] Mask Sliver [0.096mm] | 11:28:34 | 21/11/2025 | 113
[Minimum Solder Mask Sliver Constraint Violation] | BLE-Control.PcbDoc | Advanced PCB | Minimum Solder Mask Sliver Constraint: (0.096mm < 0.254mm) Between Pad IC3-27(127.262mm,16.78mm) on L1_TOP And Pad IC3-49(123.91mm,18.53mm) on L1_TOP [Top Solder] Mask Sliver [0.096mm] | 11:28:34 | 21/11/2025 | 114
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

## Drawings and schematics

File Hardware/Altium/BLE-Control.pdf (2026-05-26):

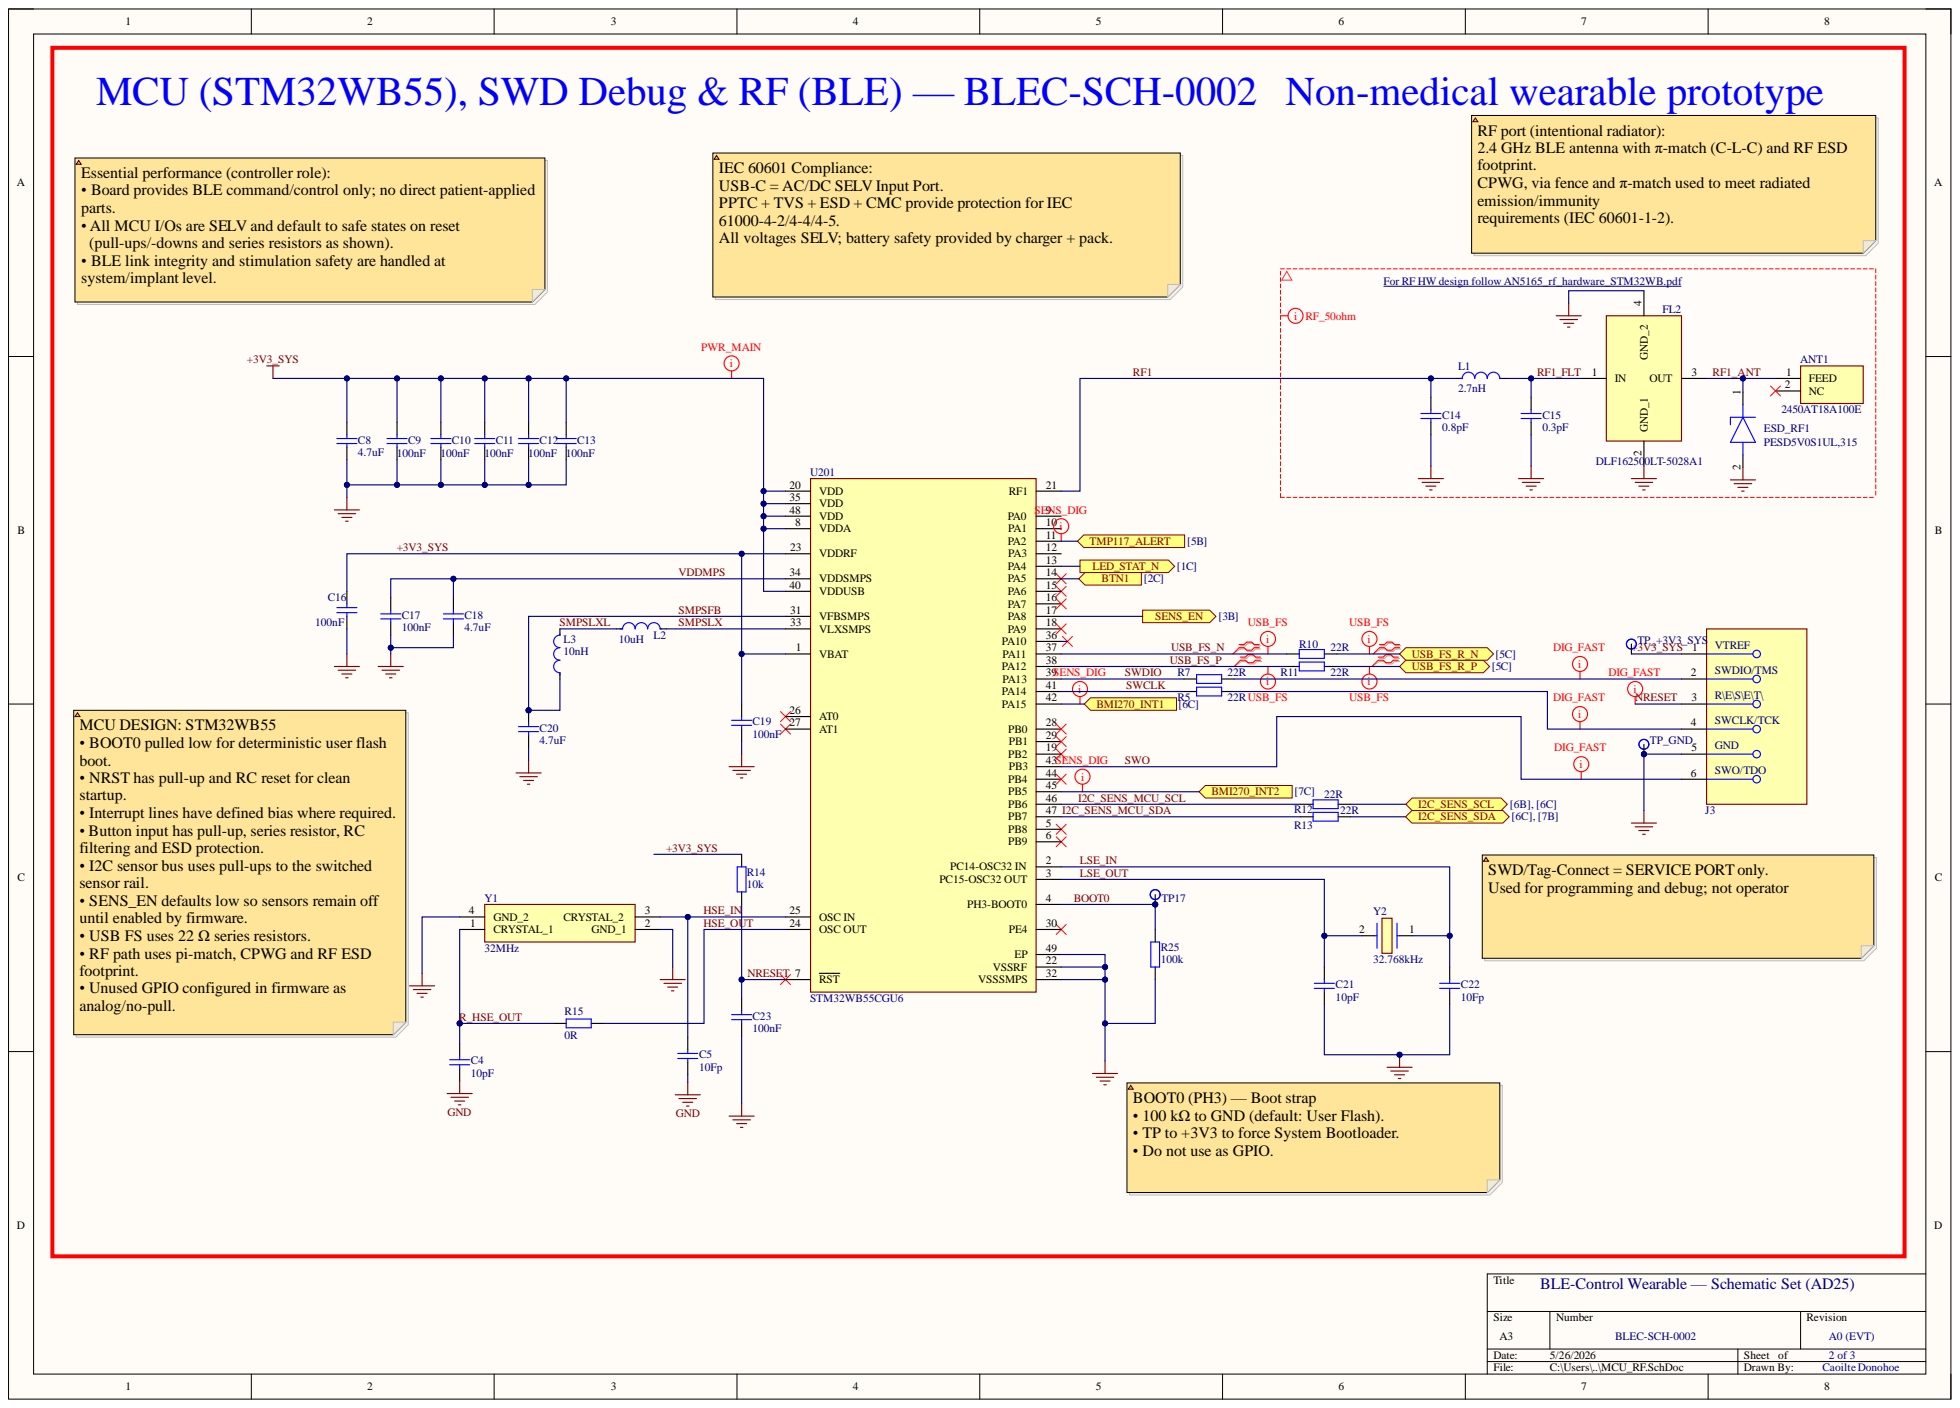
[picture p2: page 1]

MCU (STM32WB55), SWD Debug & RF (BLE) — BLEC-SCH-0002 Non-medical wearable prototype

RF port (intentional radiator):
2.4 GHz BLE antenna with π-match (C-L-C) and RF ESD
footprint.
CPWG, via fence and π-match used to meet radiated
emission/immunity
requirements (IEC 60601-1-2).

Essential performance (controller role):
• Board provides BLE command/control only; no direct patient-applied
parts.
• All MCU I/Os are SELV and default to safe states on reset
(pull-ups/-downs and series resistors as shown).
• BLE link integrity and stimulation safety are handled at
system/implant level.

IEC 60601 Compliance:
USB-C = AC/DC SELV Input Port.
PPTC + TVS + ESD + CMC provide protection for IEC
All voltages SELV; battery safety provided by charger + pack.

For RF HW design follow AN5165_rf_hardware_STM32WB.pdf (https://www.st.com/resource/en/application_note/an5165-how-to-develop-rf-hardware-using-stm32wb-microcontrollers-stmicroelectronics.pdf)

VDD 35 | SENS_DIG TMP117_ALERT [5B] LED_STAT_N [1C] BTN1 [2C] SENS_EN [3B] USB_FS USB_FS

VDDA 8 | i

VDDMPS | | | | VDDSMPS 34

VDDUSB 40

SMPSFB | | | | VFBSMPS 31

L3 L2 10uH 10nH | | | VLXSMPS 33

MCU DESIGN: STM32WB55
• BOOT0 pulled low for deterministic user flash
boot.
• NRST has pull-up and RC reset for clean
startup.
• Interrupt lines have defined bias where required.
• Button input has pull-up, series resistor, RC
filtering and ESD protection.
• I2C sensor bus uses pull-ups to the switched
sensor rail.
• SENS_EN defaults low so sensors remain off
until enabled by firmware.
• USB FS uses 22 Ω series resistors.

SWD/Tag-Connect = SERVICE PORT only.
Used for programming and debug; not operator

HSE_OUT

• RF path uses pi-match, CPWG and RF ESD
• Unused GPIO configured in firmware as
analog/no-pull.

NRESET | RST 7

BOOT0 (PH3) — Boot strap
• 100 kΩ to GND (default: User Flash).
• TP to +3V3 to force System Bootloader.
• Do not use as GPIO.

BLE-Control Wearable — Schematic Set (AD25)

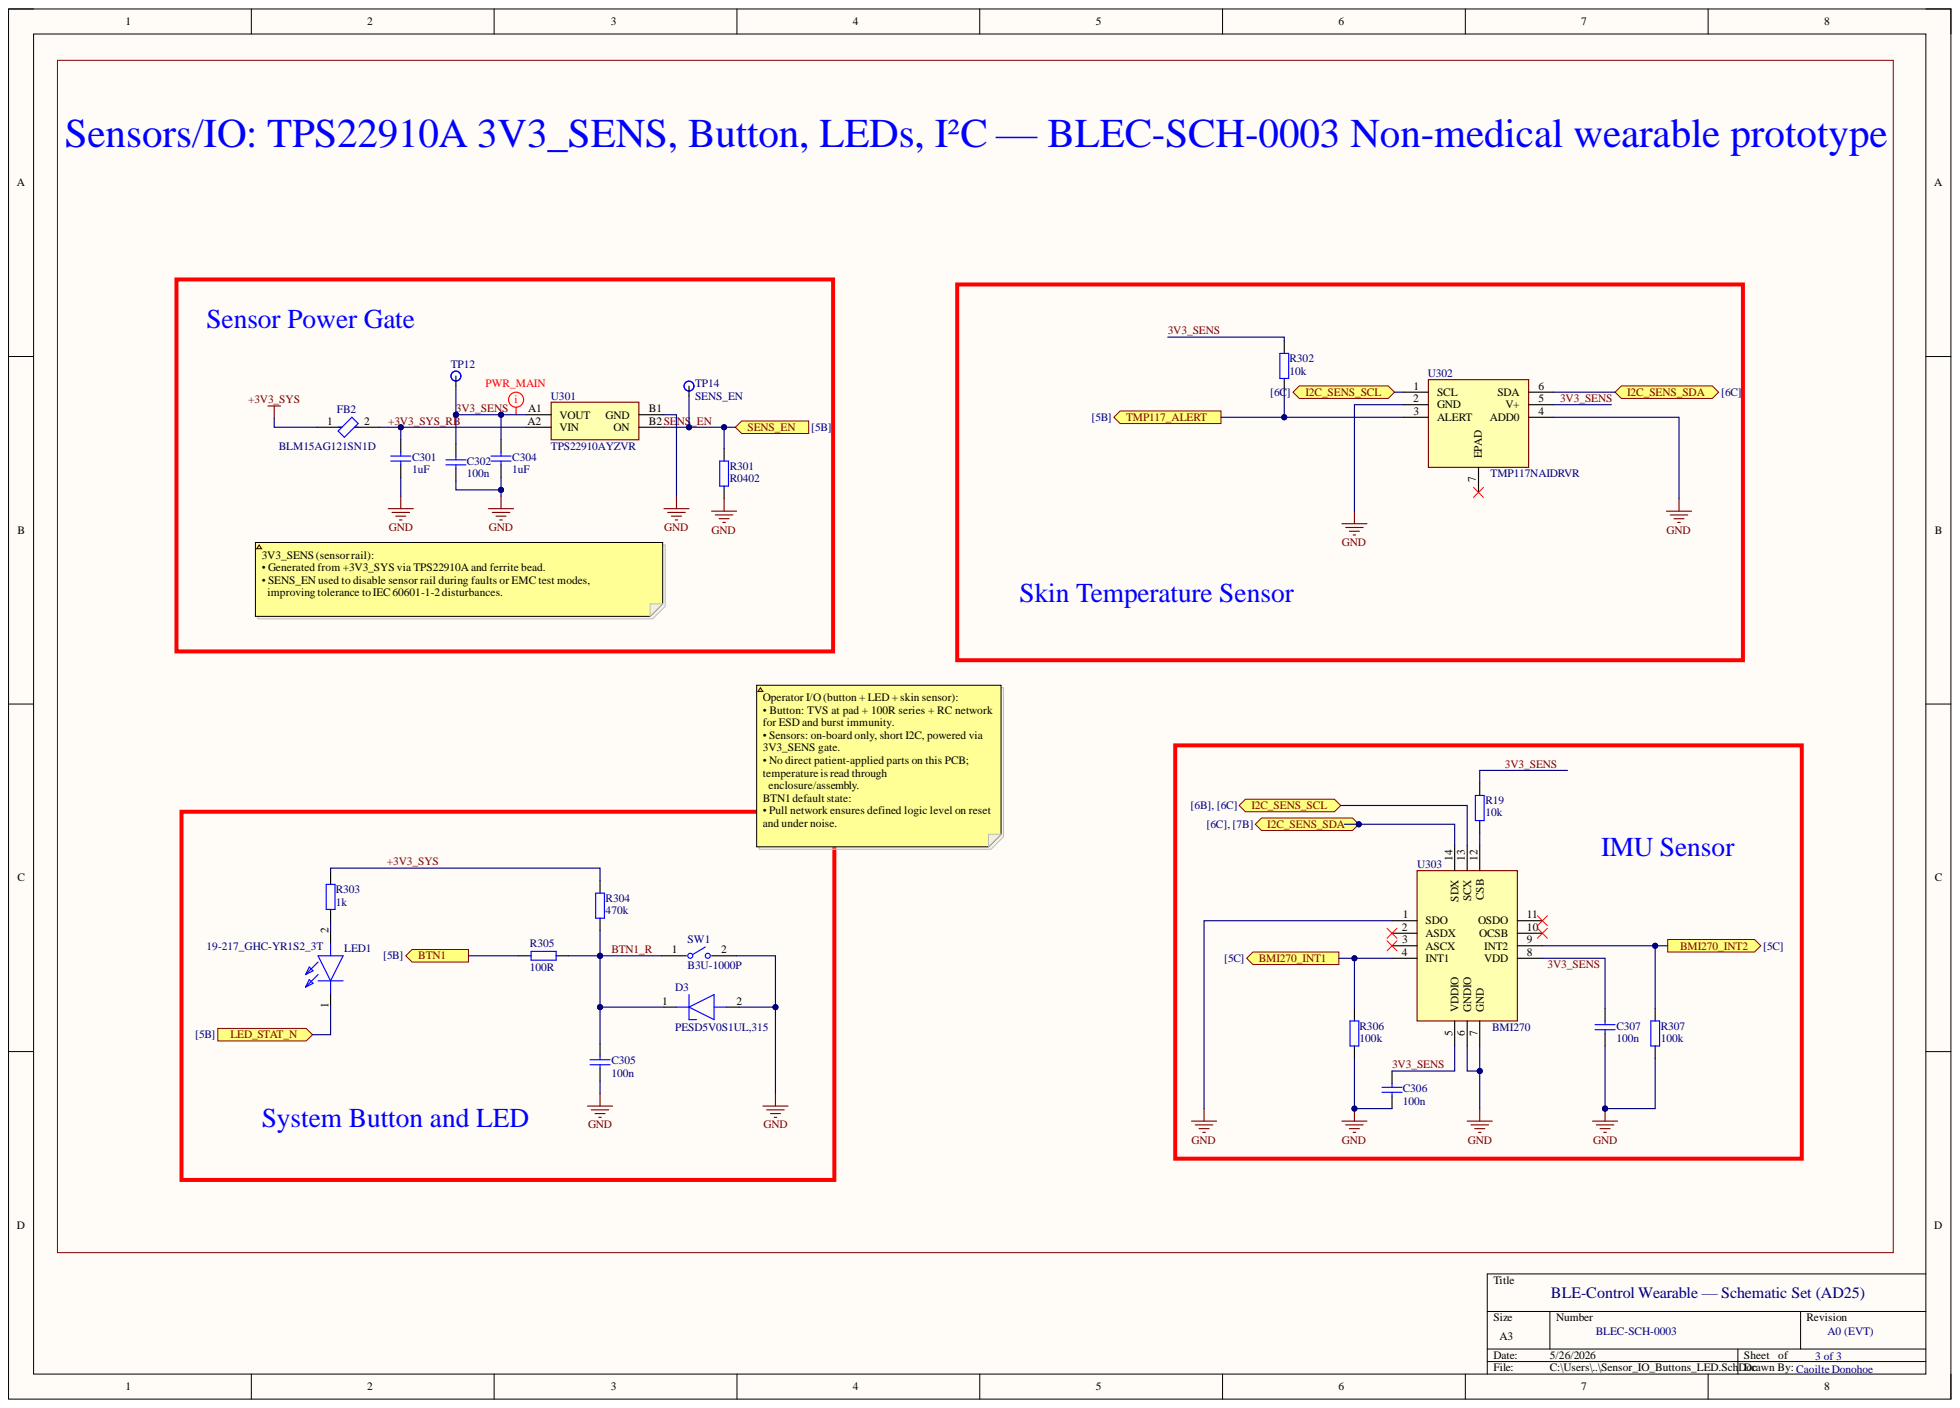
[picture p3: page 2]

Sensors/IO: TPS22910A 3V3_SENS, Button, LEDs, I²C — BLEC-SCH-0003 Non-medical wearable prototype

3V3_SENS (sensorrail):
• Generated from +3V3_SYS via TPS22910A and ferrite bead.
• SENS_EN used to disable sensor rail during faults or EMC test modes,
improving tolerance to IEC60601-1-2 disturbances.

Operator I/O (button + LED + skin sensor):
• Button: TVS at pad + 100R series + RC network
for ESD and burst immunity.
• Sensors: on-board only, short I2C, powered via
3V3_SENS gate.
• No direct patient-applied parts on this PCB;
temperature isread through
enclosure/assembly.
BTN1 defaultstate:
• Pull network ensures defined logic level on reset
and under noise.

GND 7 VDD 8 INT2 9 OCSB 10 OSDO 11

System Button and LED

BLE-Control Wearable — Schematic Set (AD25)

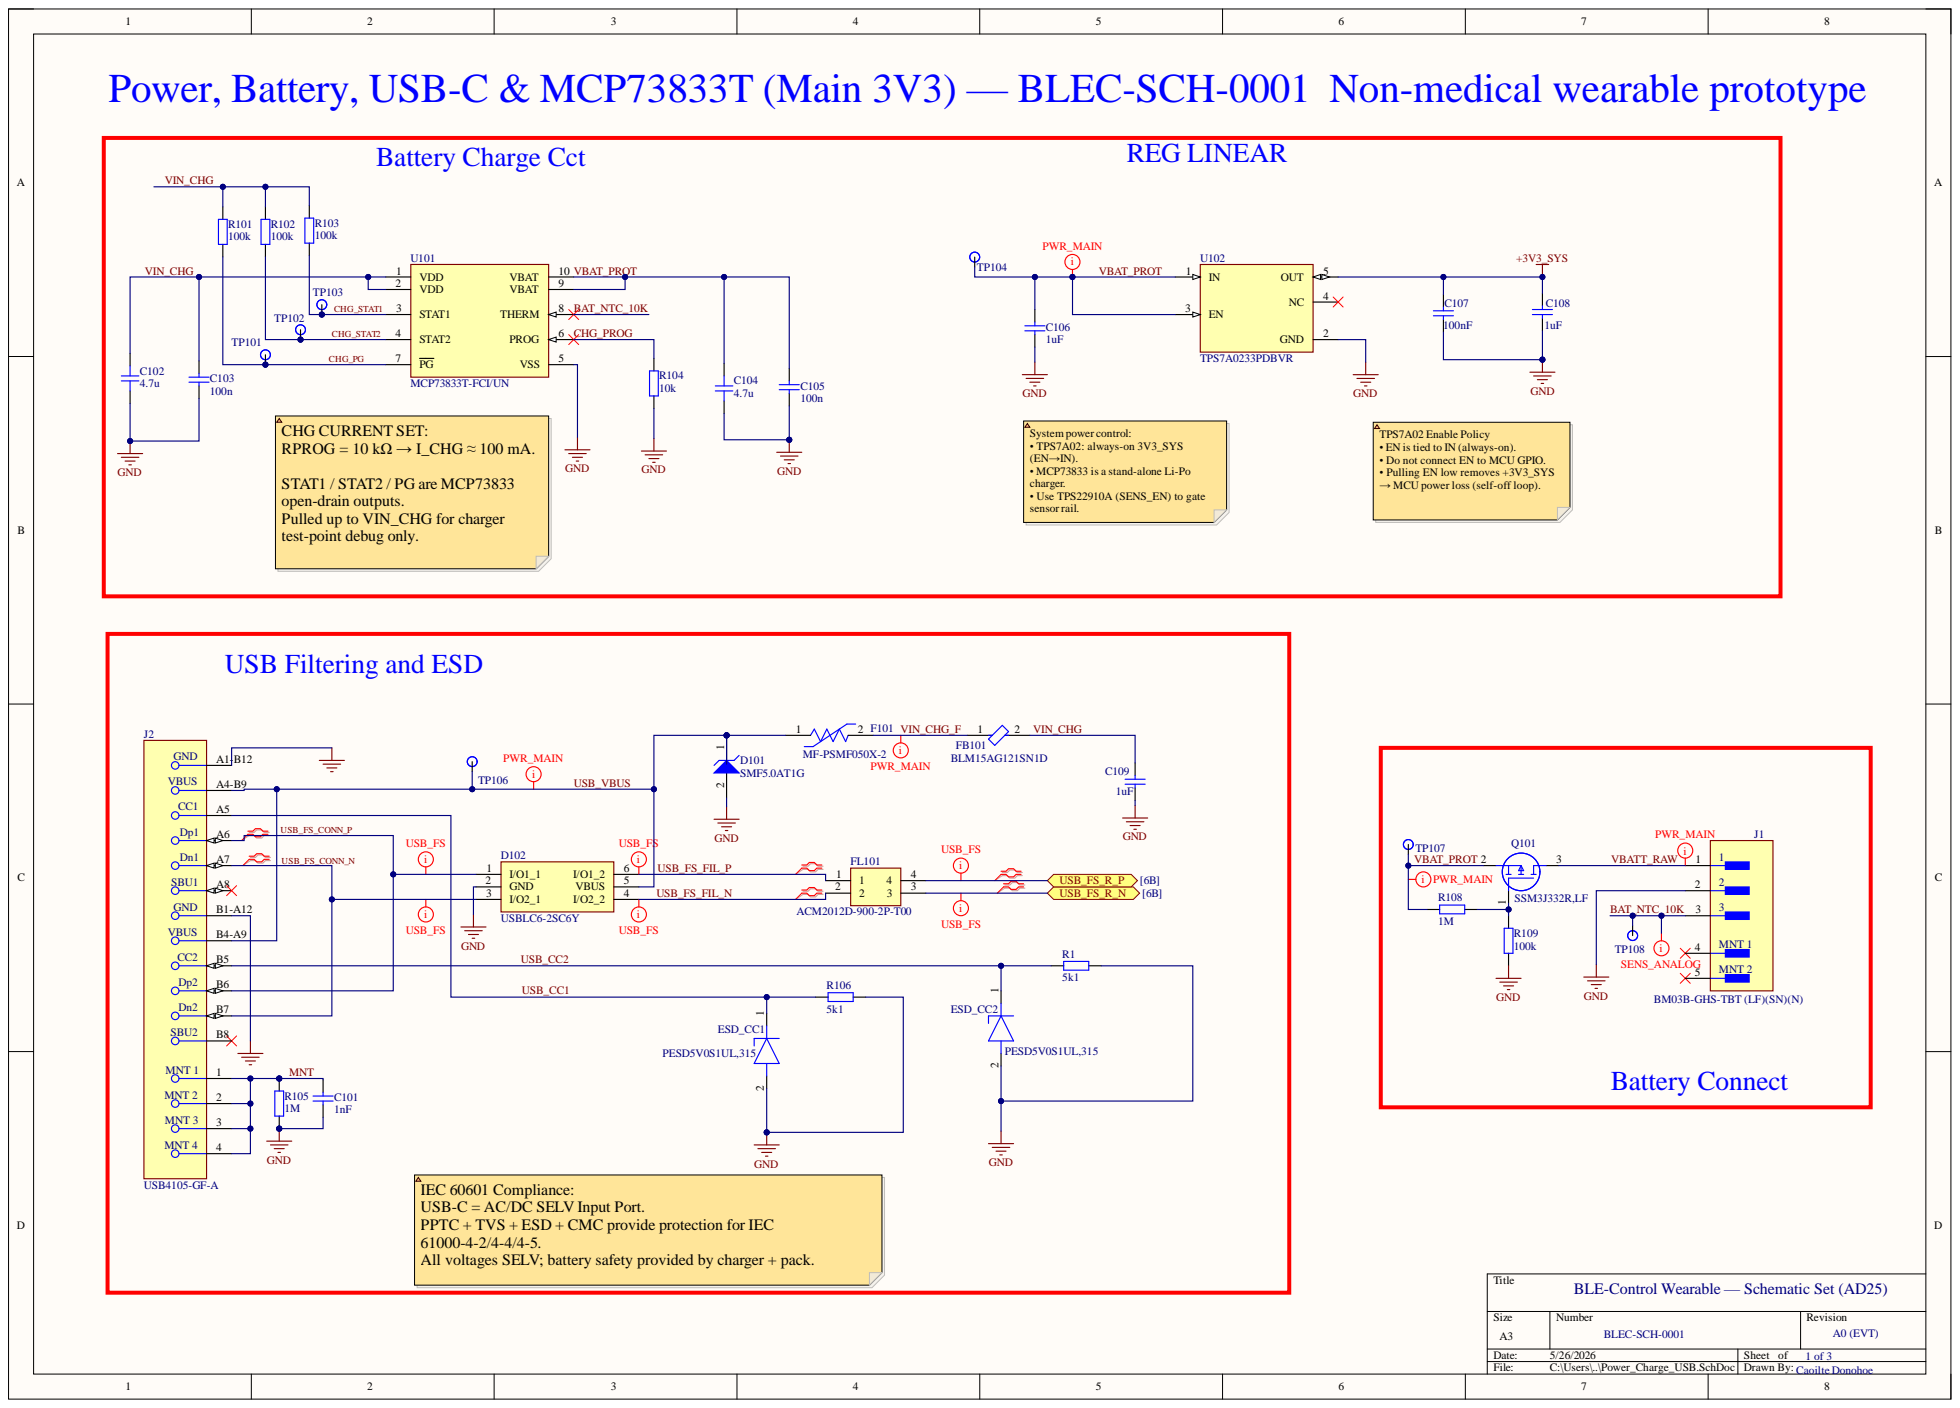
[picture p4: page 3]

Power, Battery, USB-C & MCP73833T (Main 3V3) — BLEC-SCH-0001 Non-medical wearable prototype

System power control:
• TPS7A02: always-on 3V3_SYS
• MCP73833 is a stand-alone Li-Po
charger.
• Use TPS22910A (SENS_EN) to gate
sensorrail.

TPS7A02 Enable Policy
• EN is tied to IN (always-on).
• Do not connect EN to MCU GPIO.
• Pulling EN low removes +3V3_SYS
→ MCU power loss (self-off loop).

STAT1 / STAT2 / PG are MCP73833
open-drain outputs.
Pulled up to VIN_CHG for charger
test-point debug only.

USB Filtering and ESD

BM03B-GHS-TBT (LF)(SN)(N)

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

BLE-Control Wearable — Schematic Set (AD25)

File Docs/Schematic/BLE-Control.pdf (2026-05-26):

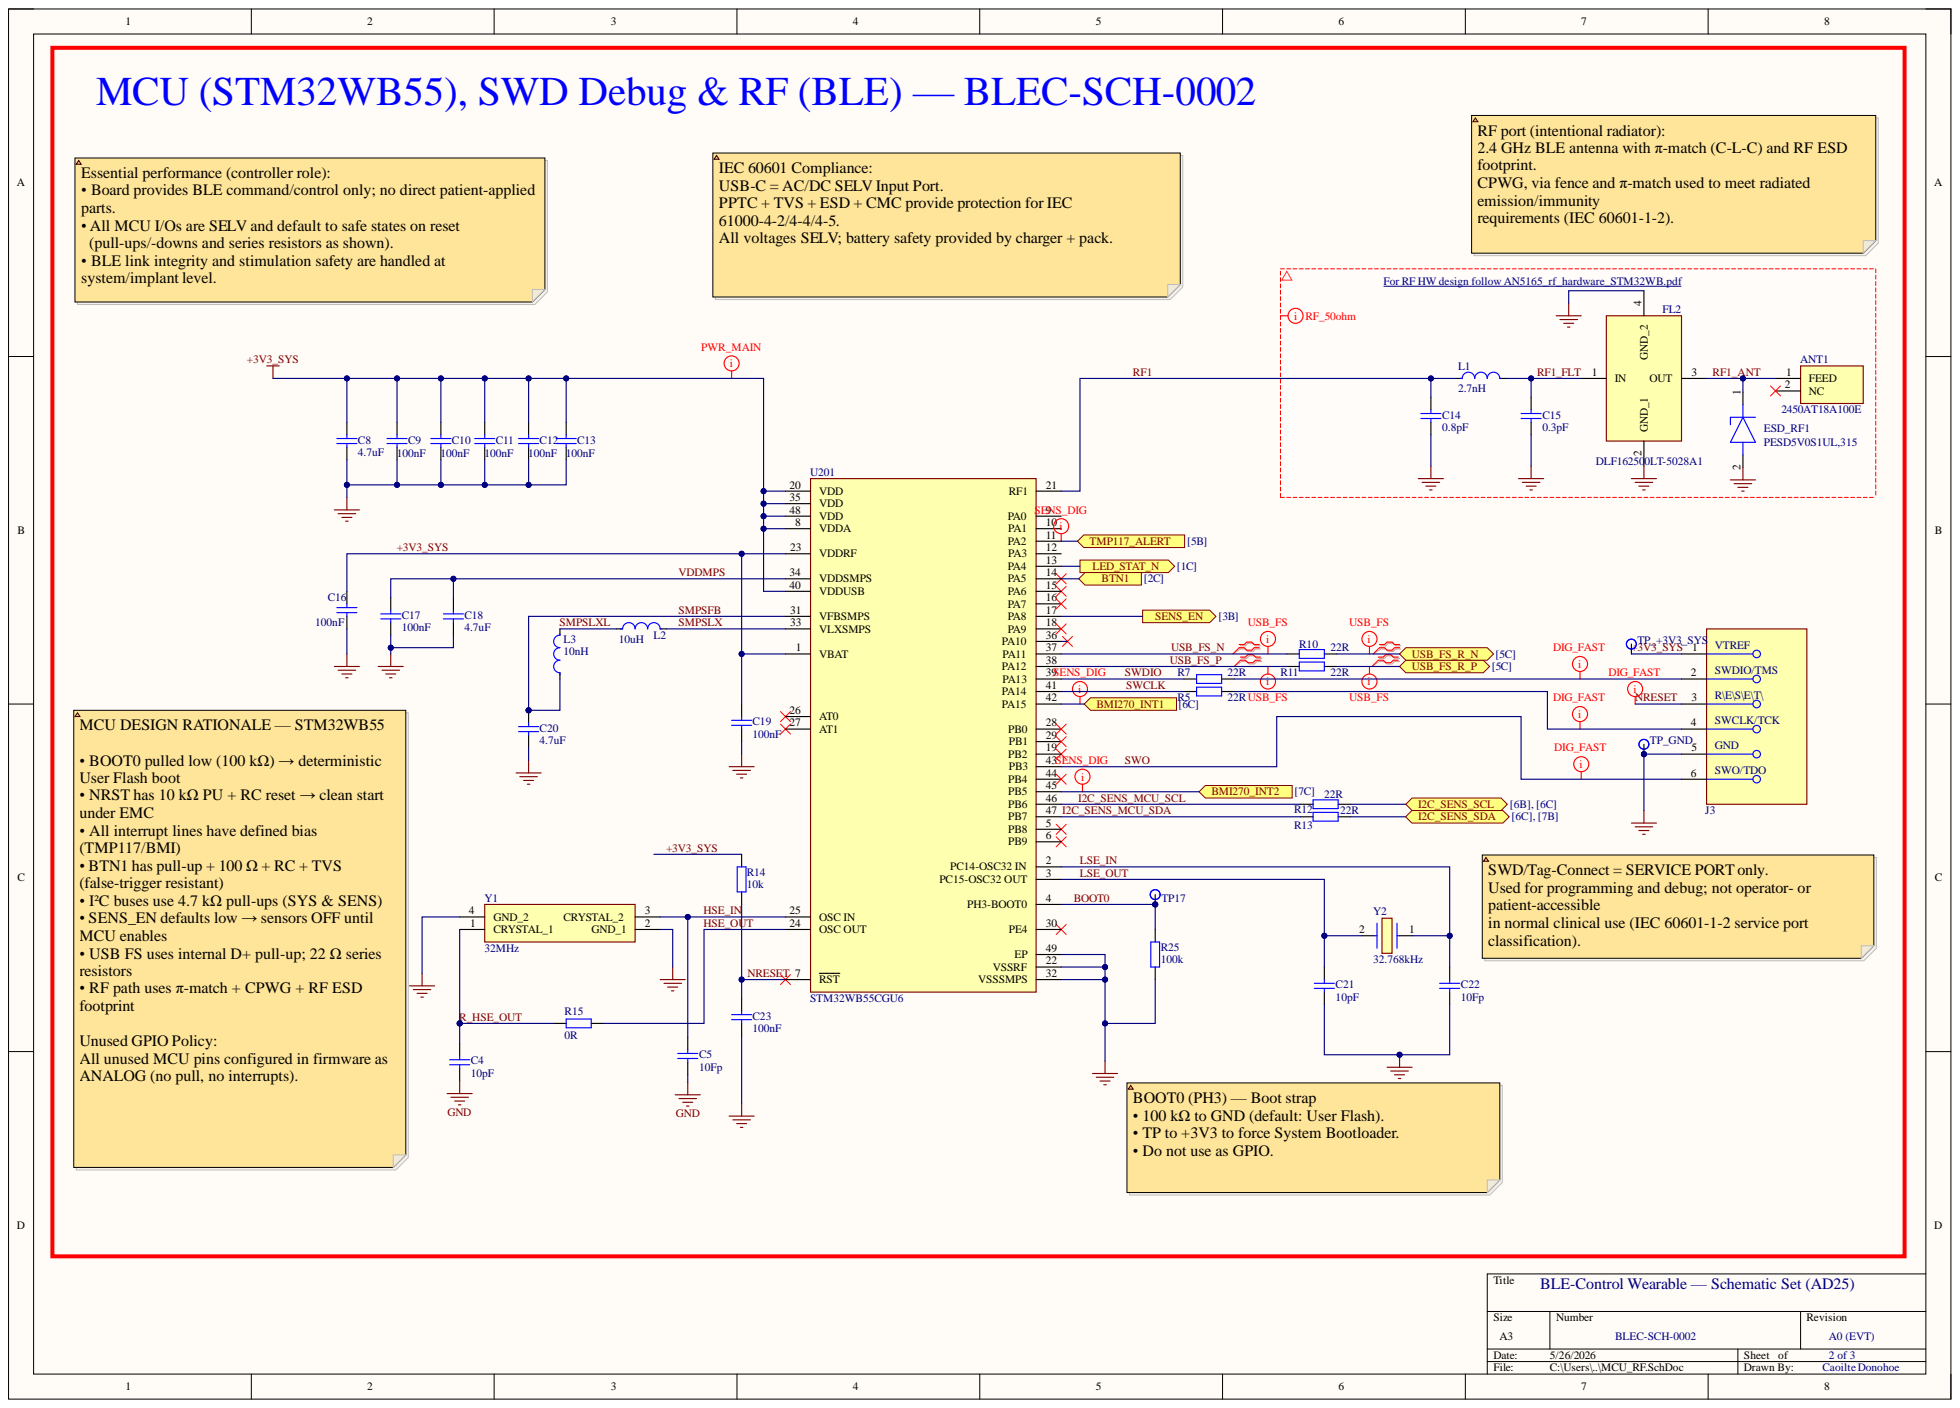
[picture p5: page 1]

MCU (STM32WB55), SWD Debug & RF (BLE) — BLEC-SCH-0002

RF port (intentional radiator):
2.4 GHz BLE antenna with π-match (C-L-C) and RF ESD
footprint.
CPWG, via fence and π-match used to meet radiated
emission/immunity
requirements (IEC 60601-1-2).

Essential performance (controller role):
• Board provides BLE command/control only; no direct patient-applied
parts.
• All MCU I/Os are SELV and default to safe states on reset
(pull-ups/-downs and series resistors as shown).
• BLE link integrity and stimulation safety are handled at
system/implant level.

IEC 60601 Compliance:
USB-C = AC/DC SELV Input Port.
PPTC + TVS + ESD + CMC provide protection for IEC
All voltages SELV; battery safety provided by charger + pack.

For RF HW design follow AN5165_rf_hardware_STM32WB.pdf (https://www.st.com/resource/en/application_note/an5165-how-to-develop-rf-hardware-using-stm32wb-microcontrollers-stmicroelectronics.pdf)

VDD 35 | SENS_DIG TMP117_ALERT [5B] LED_STAT_N [1C] BTN1 [2C] SENS_EN [3B] USB_FS USB_FS

VDDA 8 | i

VDDMPS | | | | VDDSMPS 34

VDDUSB 40

SMPSFB | | | | VFBSMPS 31

L3 L2 10uH 10nH | | | VLXSMPS 33

• BOOT0 pulled low (100 kΩ) → deterministic
User Flash boot
• NRST has 10 kΩ PU + RC reset → clean start
under EMC
• All interrupt lines have defined bias
(TMP117/BMI)
• BTN1 has pull-up + 100 Ω + RC + TVS
(false-trigger resistant)
• I²C buses use 4.7 kΩ pull-ups (SYS & SENS)
• SENS_EN defaults low → sensors OFF until
MCU enables
• USB FS uses internal D+ pull-up; 22 Ω series
resistors

SWD/Tag-Connect = SERVICE PORT only.
Used for programming and debug; not operator- or
patient-accessible
in normal clinical use (IEC 60601-1-2 service port
classification).

HSE_OUT

NRESET | RST 7

• RF path uses π-match + CPWG + RF ESD
footprint

Unused GPIO Policy:
All unused MCU pins configured in firmware as
ANALOG (no pull, no interrupts).

BOOT0 (PH3) — Boot strap
• 100 kΩ to GND (default: User Flash).
• TP to +3V3 to force System Bootloader.
• Do not use as GPIO.

BLE-Control Wearable — Schematic Set (AD25)

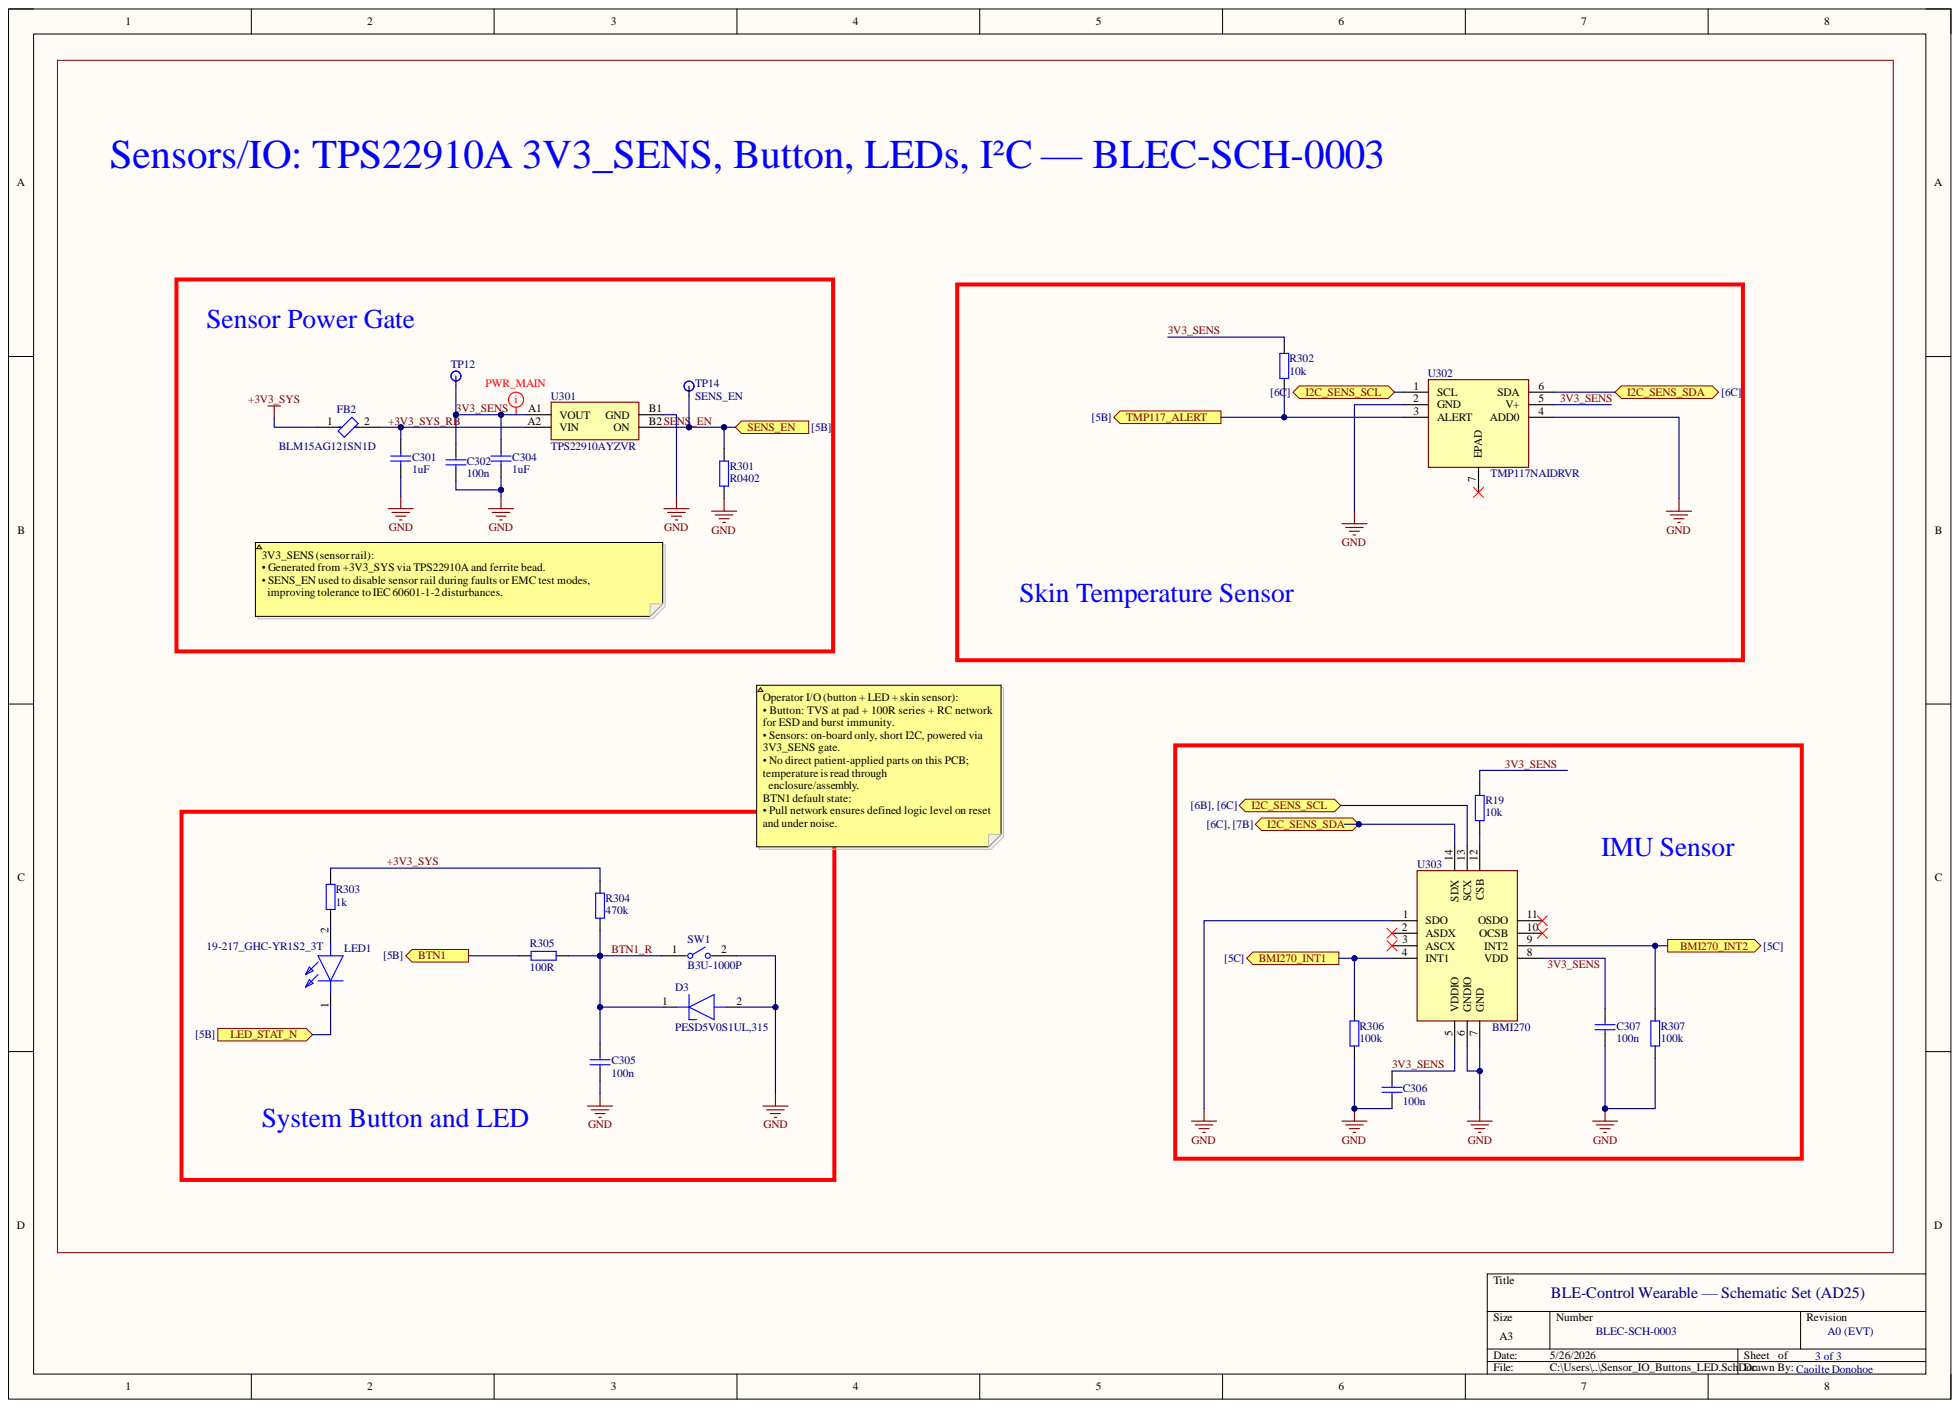
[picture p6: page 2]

Sensors/IO: TPS22910A 3V3_SENS, Button, LEDs, I²C — BLEC-SCH-0003

3V3_SENS (sensorrail):
• Generated from +3V3_SYS via TPS22910A and ferrite bead.
• SENS_EN used to disable sensor rail during faults or EMC test modes,
improving tolerance to IEC60601-1-2 disturbances.

Operator I/O (button + LED + skin sensor):
• Button: TVS at pad + 100R series + RC network
for ESD and burst immunity.
• Sensors: on-board only, short I2C, powered via
3V3_SENS gate.
• No direct patient-applied parts on this PCB;
temperature isread through
enclosure/assembly.
BTN1 defaultstate:
• Pull network ensures defined logic level on reset
and under noise.

GND 7 VDD 8 INT2 9 OCSB 10 OSDO 11

System Button and LED

BLE-Control Wearable — Schematic Set (AD25)

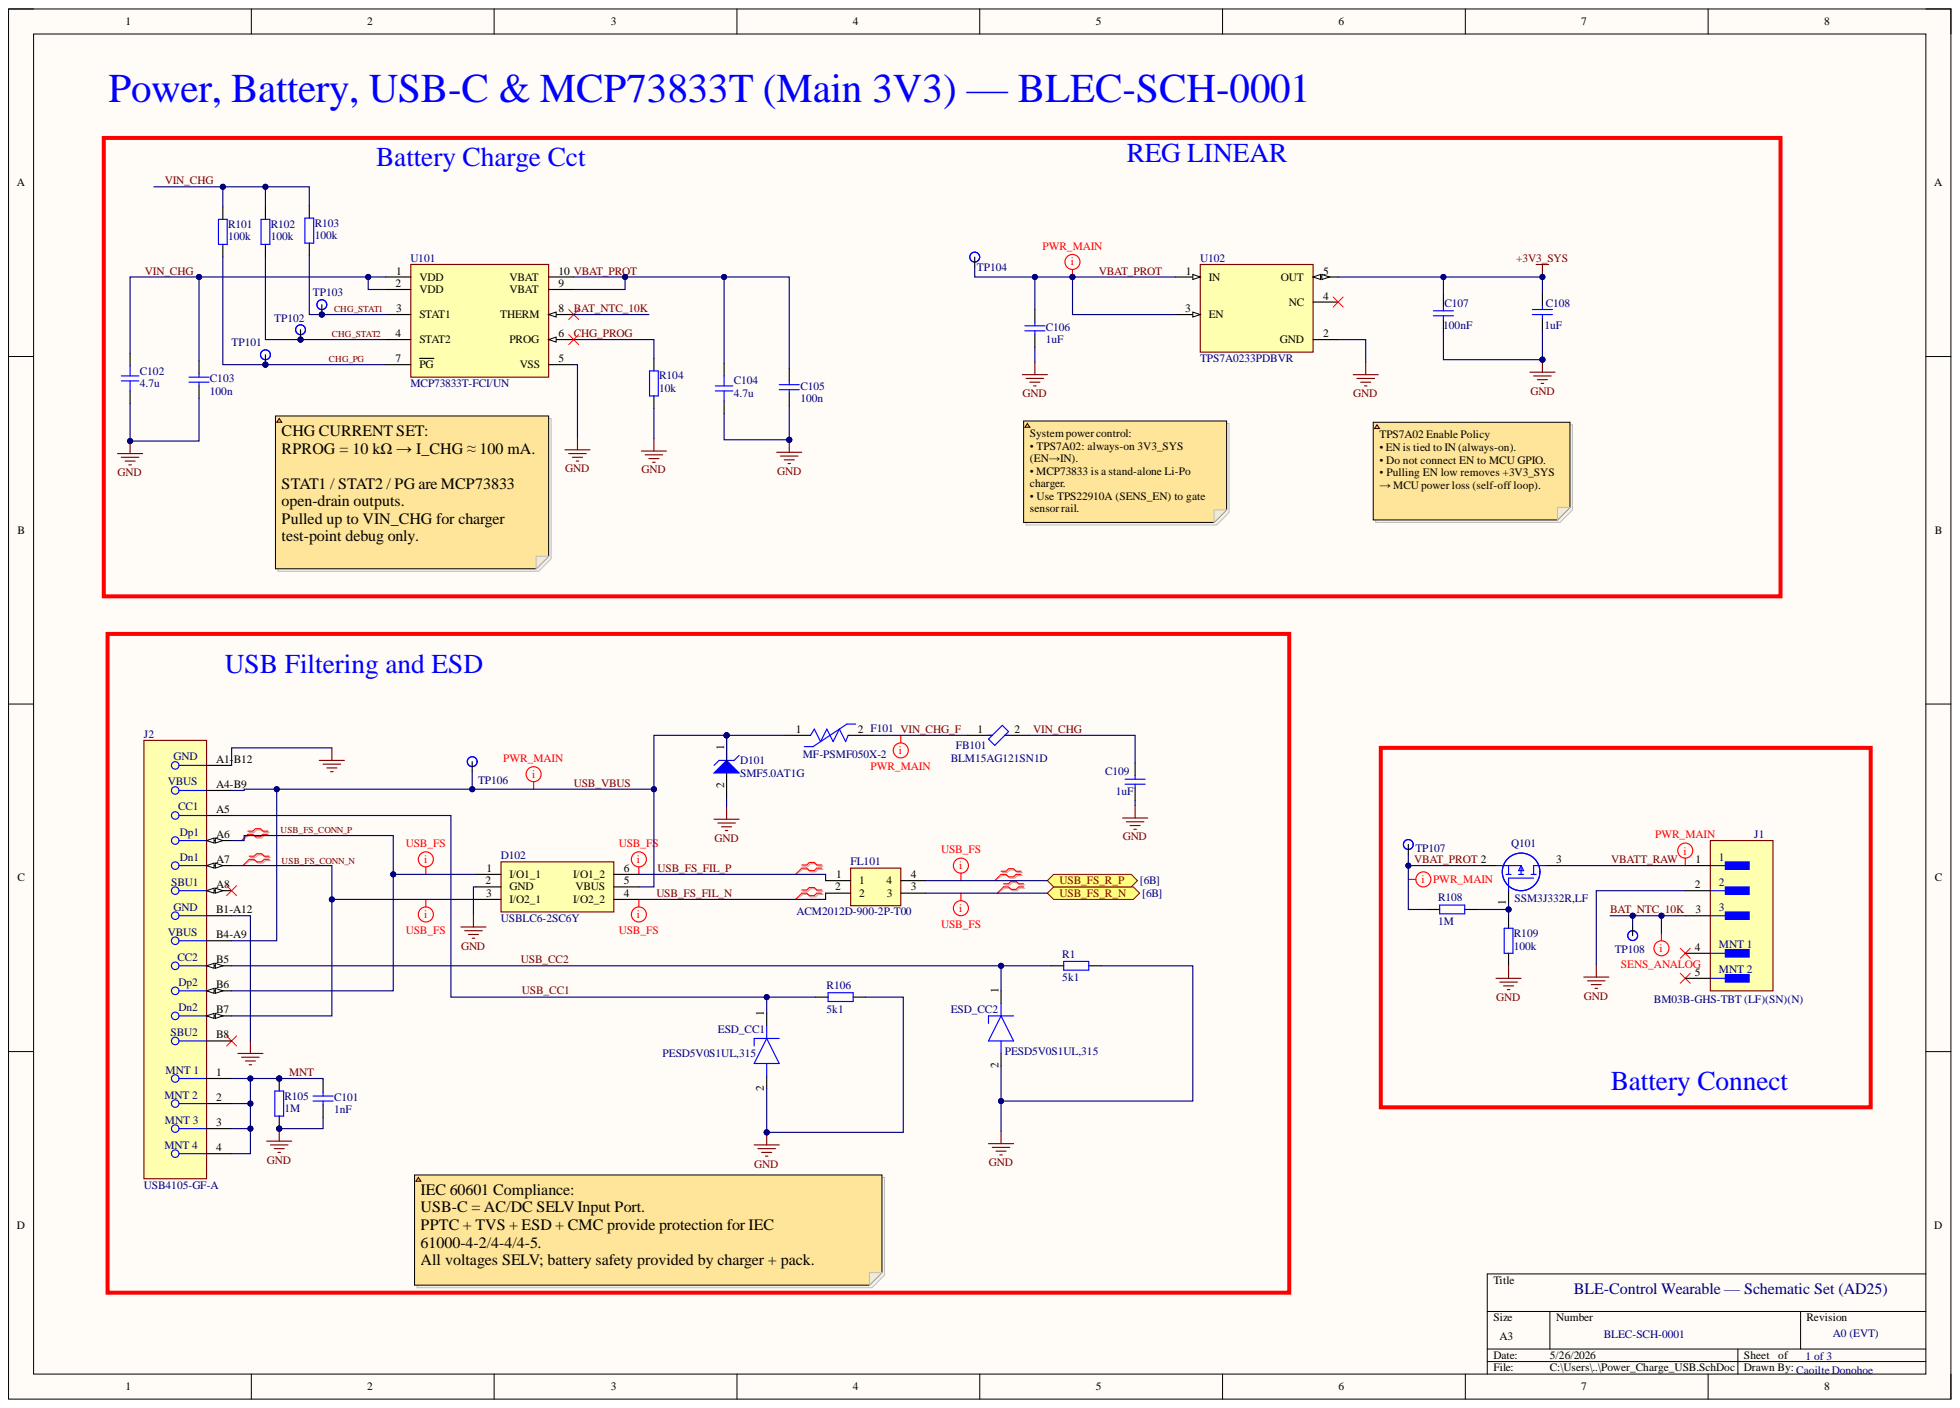
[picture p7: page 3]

Power, Battery, USB-C & MCP73833T (Main 3V3) — BLEC-SCH-0001

System power control:
• TPS7A02: always-on 3V3_SYS
• MCP73833 is a stand-alone Li-Po
charger.
• Use TPS22910A (SENS_EN) to gate
sensorrail.

TPS7A02 Enable Policy
• EN is tied to IN (always-on).
• Do not connect EN to MCU GPIO.
• Pulling EN low removes +3V3_SYS
→ MCU power loss (self-off loop).

STAT1 / STAT2 / PG are MCP73833
open-drain outputs.
Pulled up to VIN_CHG for charger
test-point debug only.

USB Filtering and ESD

BM03B-GHS-TBT (LF)(SN)(N)

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

BLE-Control Wearable — Schematic Set (AD25)

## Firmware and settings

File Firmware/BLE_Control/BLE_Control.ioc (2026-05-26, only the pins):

Mcu.UserName=STM32WB55CGUx
PA0.GPIO_Label=BMI270_INT1
PA0.Signal=GPXTI0
PA1.GPIO_Label=BMI270_INT2
PA1.Signal=GPXTI1
PA11.Signal=USB_DM
PA12.Signal=USB_DP
PA13.Signal=SYS_JTMS-SWDIO
PA14.Signal=SYS_JTCK-SWCLK
PA8.GPIO_Label=SENS_EN
PA8.Signal=GPIO_Output
PB0.GPIO_Label=LED_STAT_N
PB0.Signal=GPIO_Output
PB3.Signal=SYS_JTDO-SWO
PB6.Signal=I2C1_SCL
PB7.Signal=I2C1_SDA
PC14-OSC32_IN.Signal=RCC_OSC32_IN
PC15-OSC32_OUT.Signal=RCC_OSC32_OUT

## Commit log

2025-10-23 STM32WB55xx BLE enabled STM32 data sheet
2025-10-23 Altium File Structure added
    [BLE_Control.PrjPcb, VariantMatrix.xlsx]
2025-10-24 Added Altium files
    [TopLevel.SchDoc, VariantMatrix.xlsx]
2025-10-25 Added build plans and added schematic sheets in Altium
    [TopLevel.SchDoc, [1] TopLevel.SchDoc, [2] MCU_RF.SchDoc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]
2025-10-25 Changed file name BLE‑Control — Build Plan_AD25
2025-10-26 Add section: RF & PER Testing (STM32CubeMonitor-RF)
2025-10-26 STM32CubeIDE file structure added
2025-10-26 docs: add STM32CubeIDE firmware reference + link to Firmware/BLE_Control/README.md
2025-10-26 Update README.mddocs: add STM32CubeIDE firmware reference + link to Firmware/BLE_Control/README.md
2025-10-26 BLE-Control — Hardware ⇄ Firmware Pin Map (Single Source)
2025-10-26 Update READMdocs: create single-source pin map and de-duplicate READMEsE.md
    - Add Docs/BLE_Control_PinMap.md (canonical HW⇄FW pin table for STM32WB55CG).
    - Hardware/Firmware READMEs now link to the canonical file; removed duplicate tables.
    - Policy: only edit pin/function mappings in the canonical doc.
2025-10-28 Commit changes
    [BLE_Control_Wearable_ActiveBOM.csv, [0] LIB_Harvest.SchDoc]
2025-10-29 Remove AD25 Altium project (keep Libraries for reuse)
    [[0] LIB_Harvest.SchDoc, [1] TopLevel.SchDoc, [2] MCU_RF.SchDoc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]
2025-10-30 Altium Design updates
    [Lib_Harvest.SchDoc]
2025-10-30 Bom update
2025-10-30 Commit and merge USB/debug with Pwr_bat charge and LDO
2025-10-31 Added Datasheets
    [Power_Batt_Charge_LDO.SchDoc, Power_Charge_USB.SchDoc, USB_Debug.SchDoc]
2025-10-31 update library
    [BLE-Control.PrjPcb, Power_Charge_USB.SchDoc]
2025-11-04 Power And GND pins
    [BLE-Control.PcbDoc, MCU_RF.SchDoc, Power_Charge_USB.SchDoc]
2025-11-05 MCU_RF circuits
    [BLE-Control.PcbDoc, BLE-Control.PrjPcb, MCU_RF.SchDoc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]
2025-11-05 Create # BLE-Control — BOM (Grouped).md
2025-11-05 Update # BLE-Control — BOM (Grouped).md
2025-11-06 readme update
    [BLE-Control.PcbDoc, MCU_RF.SchDoc, Power_Charge_USB.SchDoc]
2025-11-06 schematic updates
    [MCU_RF.SchDoc, Power_Charge_USB.SchDoc]
2025-11-07 move to landing page "BLE-Control_Wearable_Schematic_Guide_AD25_v2.md"
2025-11-07 Sensor_IO_Buttons_LED.SchDoc details
2025-11-15 Updated library and README
    [Lib_Harvest.SchDoc, MCU_RF.SchDoc, Power_Charge_USB.SchDoc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]
2025-11-15 Battery Pack Docs
2025-11-16 Repo Layout Change
    [BLE-Control.PrjPcb, MCU_RF.SchDoc, Power_Charge_USB.SchDoc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]
2025-11-17 Compliance Folder created
    [MCU_RF.SchDoc, Power_Charge_USB.SchDoc, Sensor_IO_Buttons_LED.SchDoc]
2025-11-17 Added Safety_Analysis_ISO14971.md
    [MCU_RF.SchDoc, Power_Charge_USB.SchDoc, Sensor_IO_Buttons_LED.SchDoc]
2025-11-18 BoM folder adjustment
2025-11-18 Folder Restructure
    [BLE_Control_Wearable_ActiveBOM.csv]
2025-11-18 Added Master Schematics
2025-11-18 Added README to Docs folder: schematic, BoM, compliance, risk, battery, reports, etc.
2025-11-18 Minor changes to Schematic style
    [MCU_RF.SchDoc]
2025-11-18 Minor change to Schematic style
2025-11-18 Polish landing page with links: README1.md
2025-11-18 PCB checklist added to Hardwar/Altium/PCB
2025-11-19 Added PCB_Layout_Checklist_AD25.md
    [BLE-Control.PcbDoc]
2025-11-20 added: BLE-Control_PCB_Layout_Plan_AD25.md
    [BLE-Control.PcbDoc, BLE-Control.PrjPcb, MCU_RF.SchDoc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]
2025-11-20 Adjusted clearances to align with PCB fabs
    [BLE-Control.PcbDoc, BLE-Control.PrjPcb, MCU_RF.SchDoc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]
2025-11-20 commit pcb changes WiP
    [BLE-Control.PcbDoc]
2025-11-22 PCB Layiut updates
    [BLE-Control.PcbDoc, BLE-Control.PrjPcb, Power_Charge_USB.SchDoc]
2025-11-22 updated pcb and schematic minor changes
    [MCU_RF.SchDoc, Power_Charge_USB.SchDoc]
2025-11-26 Shematic and PCB update
    [BLE-Control.PcbDoc, MCU_RF.SchDoc, Power_Charge_USB.SchDoc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]
2026-05-21 Added image of the PCB design I created in Altium
2026-05-21 Added 3D render of PCB
2026-05-26 Adds medical-style schematic review checklist and updated BLE-Control schematic/layout reference files for the wearable redesign.
    [BLE-Control.PcbDoc, MCU_RF.SchDoc, Power_Charge_USB.SchDoc]
2026-05-26 Update Schematic
2026-05-26 Update schematic for non-medical BLE wearable redesign
    [BLE-Control.PrjPcb, MCU_RF.SchDoc, Power_Charge_USB.SchDoc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]
2026-05-26 update Schematic and checklist
    [MCU_RF.SchDoc, Power_Charge_USB.SchDoc, Sensor_IO_Buttons_LED.SchDoc]
2026-05-26 updated BLE-Control with minor changes
    [BLE-Control.PrjPcb]
2026-05-26 Minor changes in MCU_RF page
    [MCU_RF.SchDoc]
2026-05-26 Minor Changes in Schematic
    [MCU_RF.SchDoc, Sensor_IO_Buttons_LED.SchDoc]
2026-05-26 Update git repo
    [Sensor_IO_Buttons_LED.SchDoc]
2026-05-26 re-define board outline
    [BLE-Control.PcbDoc, Power_Charge_USB.SchDoc]
2026-05-27 Schematic change, PCB Board altered, Schematic Checklist updated
    [BLE-Control.PcbDoc, Power_Charge_USB.SchDoc, Sensor_IO_Buttons_LED.SchDoc]
2026-05-27 BLE-Control_PreRoute_Setup_A0. Schematic Freeze A0 EVT
    [BLE-Control.PcbDoc, Power_Charge_USB.SchDoc, Sensor_IO_Buttons_LED.SchDoc]
2026-08-12 included link to Schematic
2026-08-23 Generalize battery pack documentation
2026-08-23 Remove generated PCB message report
2026-08-23 Remove generated Altium schematic preview
2026-08-23 Remove duplicate PCB render
2026-08-23 Remove empty BOM placeholder
2026-08-23 Schematic files and DRC added
    [BLE-Control.PcbDoc, MCU_RF.SchDoc, Power_Charge_USB.SchDoc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]
